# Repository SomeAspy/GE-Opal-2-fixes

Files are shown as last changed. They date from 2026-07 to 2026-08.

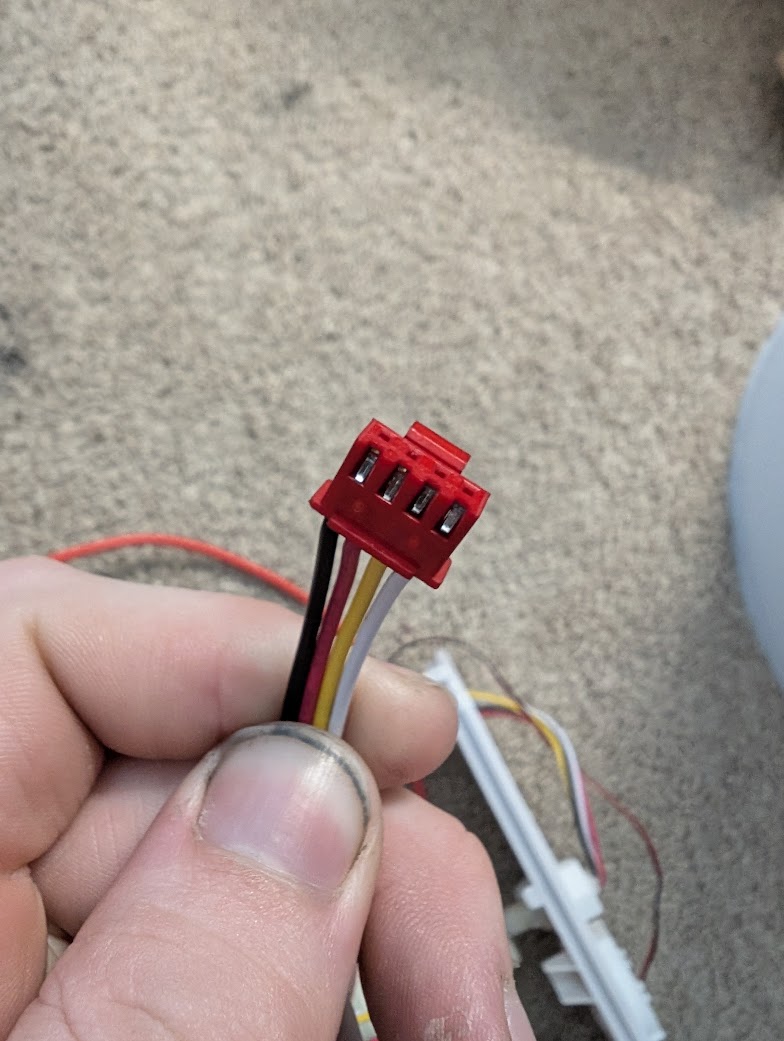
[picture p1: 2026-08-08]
images/floatConnector.jpg

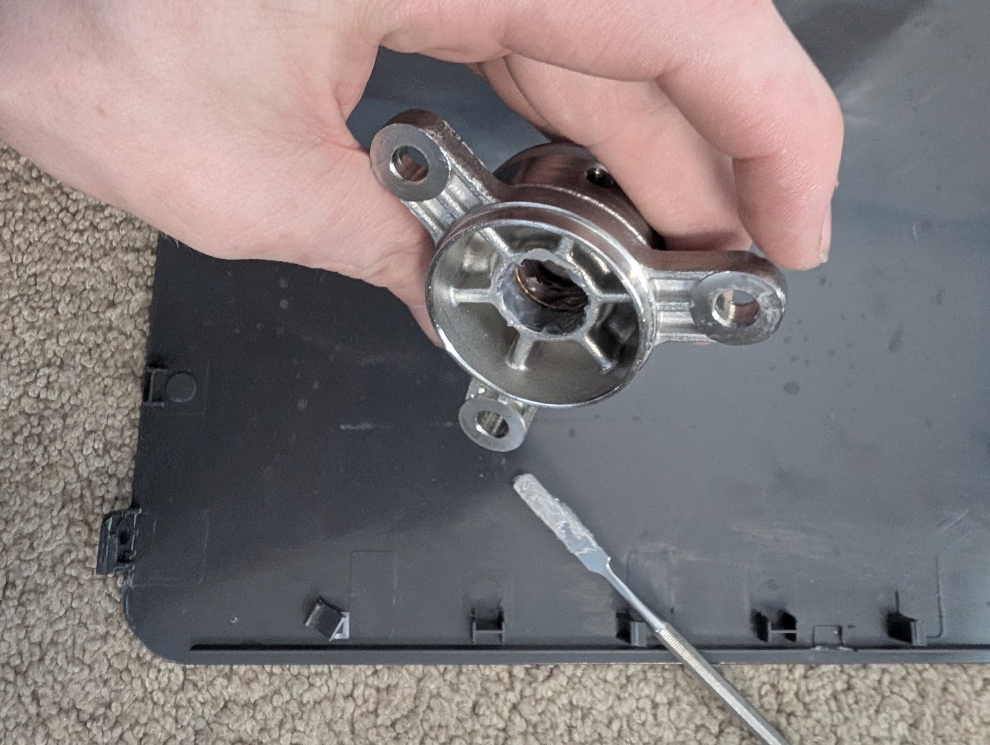
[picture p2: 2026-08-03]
images/greaseSpread.jpg

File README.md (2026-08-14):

# GE-Opal-2-fixes

This repository documents, all my attempts to make the GE Opal 2 not kill itself
(More specifically, the *GE Profile:tm: Opal:tm: 2.0 Ultra Nugget Ice Maker )

Important context to a lot of frustration here: This is a $500 dollar ice machine. It has a lifespan of 6 months to 1 year

> [!WARNING]  
> Schematics and code are not final or tested yet.

### Note on AI usage because I hate AI bullshit:

I used AI to help me understand the basics of KiCAD because I have never used it before.
I also used it to sanity check my code before I deployed it to the arduino, because I value not blowing my shit up.
I did **NOT** copy-paste code or otherwise use LLM generated material in this project.

The 2 calibration values where I used AI in the firmware are clearly marked.
If you are more skilled with calibration, your (human-made) contributions are welcome!

```cpp
augerMeter.current(MotorAmmeter, 5.76); // Calibration factor by gemini, because I hate complex math
const double currentDraw = augerMeter.calcIrms(1480); // IRM sample count by Gemini, because I can't be bothered.
```

Do **NOT** submit LLM generated issues, PRs, or use this repo in training data.

### My blog post on this

[A Scathing Review of the GE Opal 2 Nugget Ice Maker](https://blog.aspy.dev/a-scathing-review-of-the-ge-opal-2-nugget-ice-maker/)

# Background

I've tried putting lubrication on the auger ([./squeakFromShaft.md](./squeakFromShaft.md)) but it did not resolve the squeaking issue
I've decided I am going to replace the PCB with an arduino to implement a proper defrost cycle.

## Notice

As I was writing this, Reddit decided to delete the 2 year old post I was using as a reference.
Some of the more important images are available in ./images
https://web.archive.org/web/20250804095737/https://www.reddit.com/r/IceChewersAnonymous/comments/1hxlbkg/fixing_the_opal_20/

## The Problem

The GE Opal ice maker has well-known issues where it will start to fail after about a year of use, and in some cases, prior.
The machine is incredibly high maintenance, [with GE recommending running bleach through the machine](https://products.geappliances.com/appliance/gea-support-search-content?contentId=000060634) ([archive.org capture](https://web.archive.org/web/20260716162758/https://products.geappliances.com/appliance/gea-support-search-content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))

There is even (as of writing) [an ongoing class action](https://classlawdc.com/2026/01/21/ge-profile-opalnugget-ice-maker-series-1-0-and-2-0-defective-product-investigation/)

These machines do not fail gracefully, often making screeching and whining noises due to the internal parts getting frozen and locked up. This commonly involves the destruction of the gearbox, auger, and/or bearings.

Browsing Reddit reveals many owners have constant issues with these machines, with one redditor even claiming to go through 4 machines in 2 years. Despite its flaws, this machine is well liked by r/IceChewersAnonymous, though they also agree that it has significant longevity issues. [A quick search shows the love/hate the community has for it.](https://www.reddit.com/r/IceChewersAnonymous/search/?q=opal+2)

More importantly, several members of the community have taken attempts to repair the machine pretty far.

- https://www.reddit.com/r/IceChewersAnonymous/comments/1ophadu/opal_20_repair_update/
- https://www.reddit.com/r/IceChewersAnonymous/comments/1hxlbkg/fixing_the_opal_20/
- https://www.reddit.com/r/IceChewersAnonymous/comments/159ts6e/ge_opal_20_add_water_fix/

# Piping

Piping

# Nominal voltages recorded from the opal 2 ice maker during operation

| Part | Connector Type | Voltage |
| --- | --- | --- |
| UV Light | JST XH 2-pin connector  | 12V DC  |
| Compressor | JST VHR 3-pin connector | 120V AC |
| Auger Motor | JST VHR 3-pin connector | 120V AC |
| Pump | JST XH 2-pin connector  | 12V DC  |
| Fan | JST XH 2-pin connector  | 12V DC  |
| WiFi Board | TBD | TBD |
| Front Panel | TBD | TBD |
| Ice Box LED | JST XH 2-pin connector  | 5V DC |
| Ice box presence switch | JST XH 2-pin connector  | 5V DC |
| Internal Tank Floats | JST XH 4-pin connector  | 5V DC |
| IR LED For Capacity | JST XH 2-pin connector  | 5V DC |
| IR Receiver | JST XH 2-pin connector  | 5V DC |
| AC Input | JST VHR 3-pin connector | 120V AC |

- Internal Tank Floats (4 wires, 2 floats)
  - Black & Red: Lower float (float low = closed circuit)
  - Yellow & White: Upper float (float high = closed circuit)

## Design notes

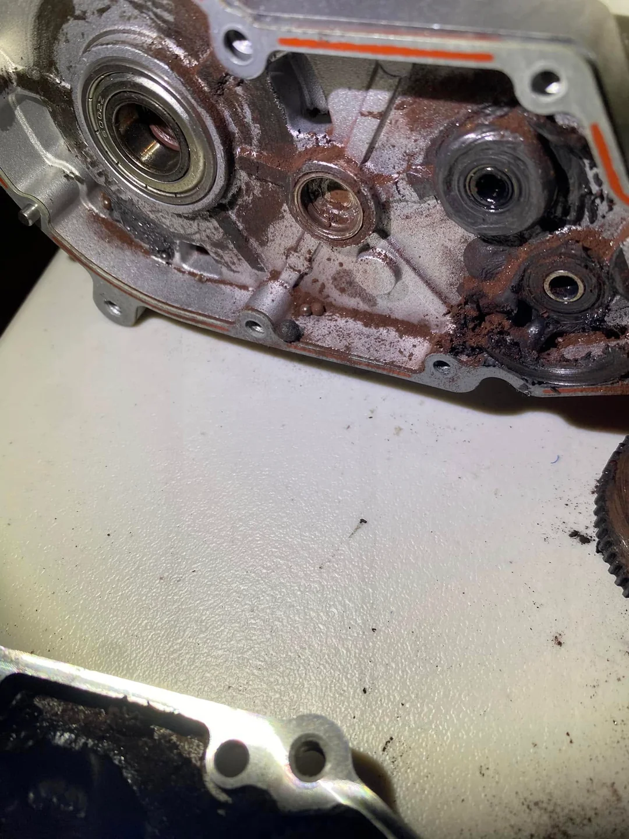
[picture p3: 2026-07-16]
images/shreddedGearbox.webp

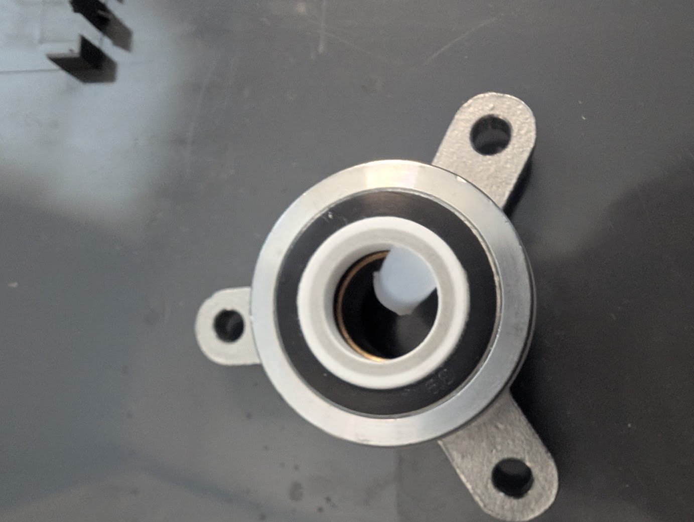
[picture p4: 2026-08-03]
images/greasedBushing.jpg

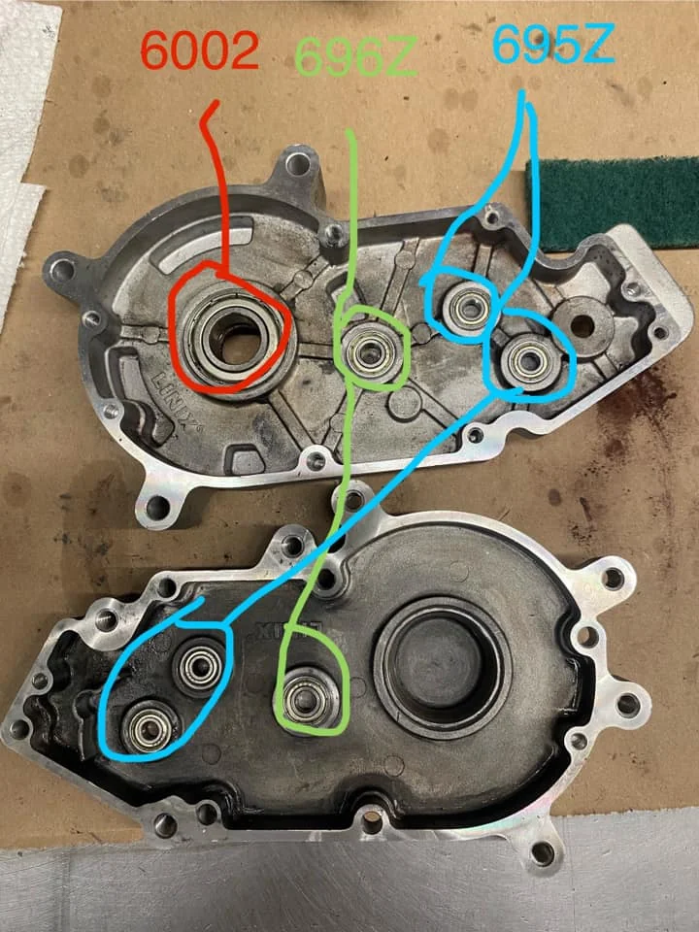
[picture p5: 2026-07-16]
images/bearingSizes.webp

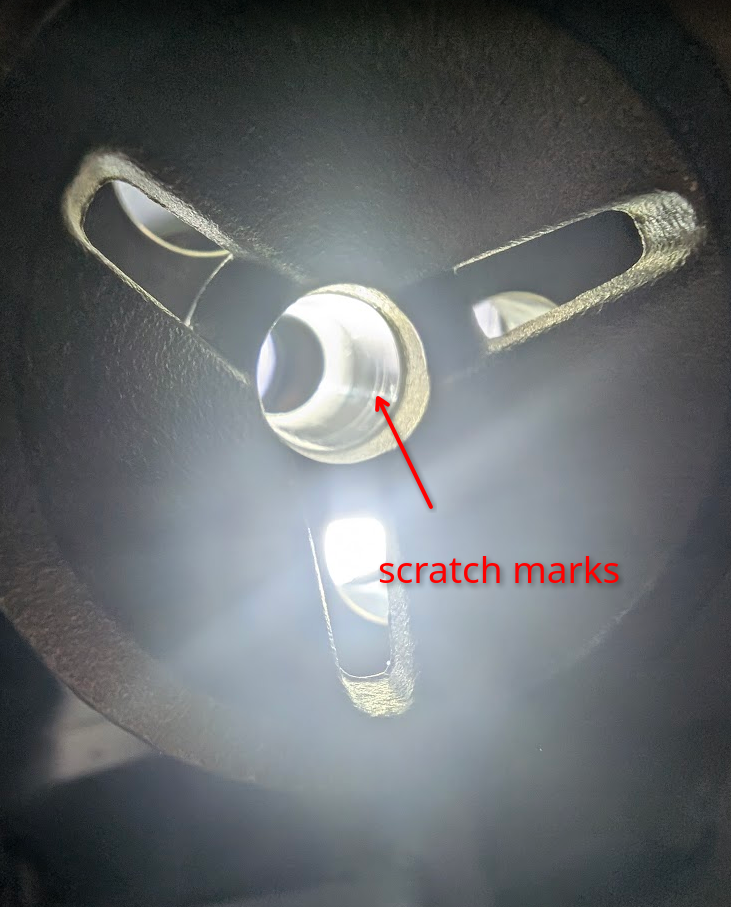
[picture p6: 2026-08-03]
images/scratchedBushing.png

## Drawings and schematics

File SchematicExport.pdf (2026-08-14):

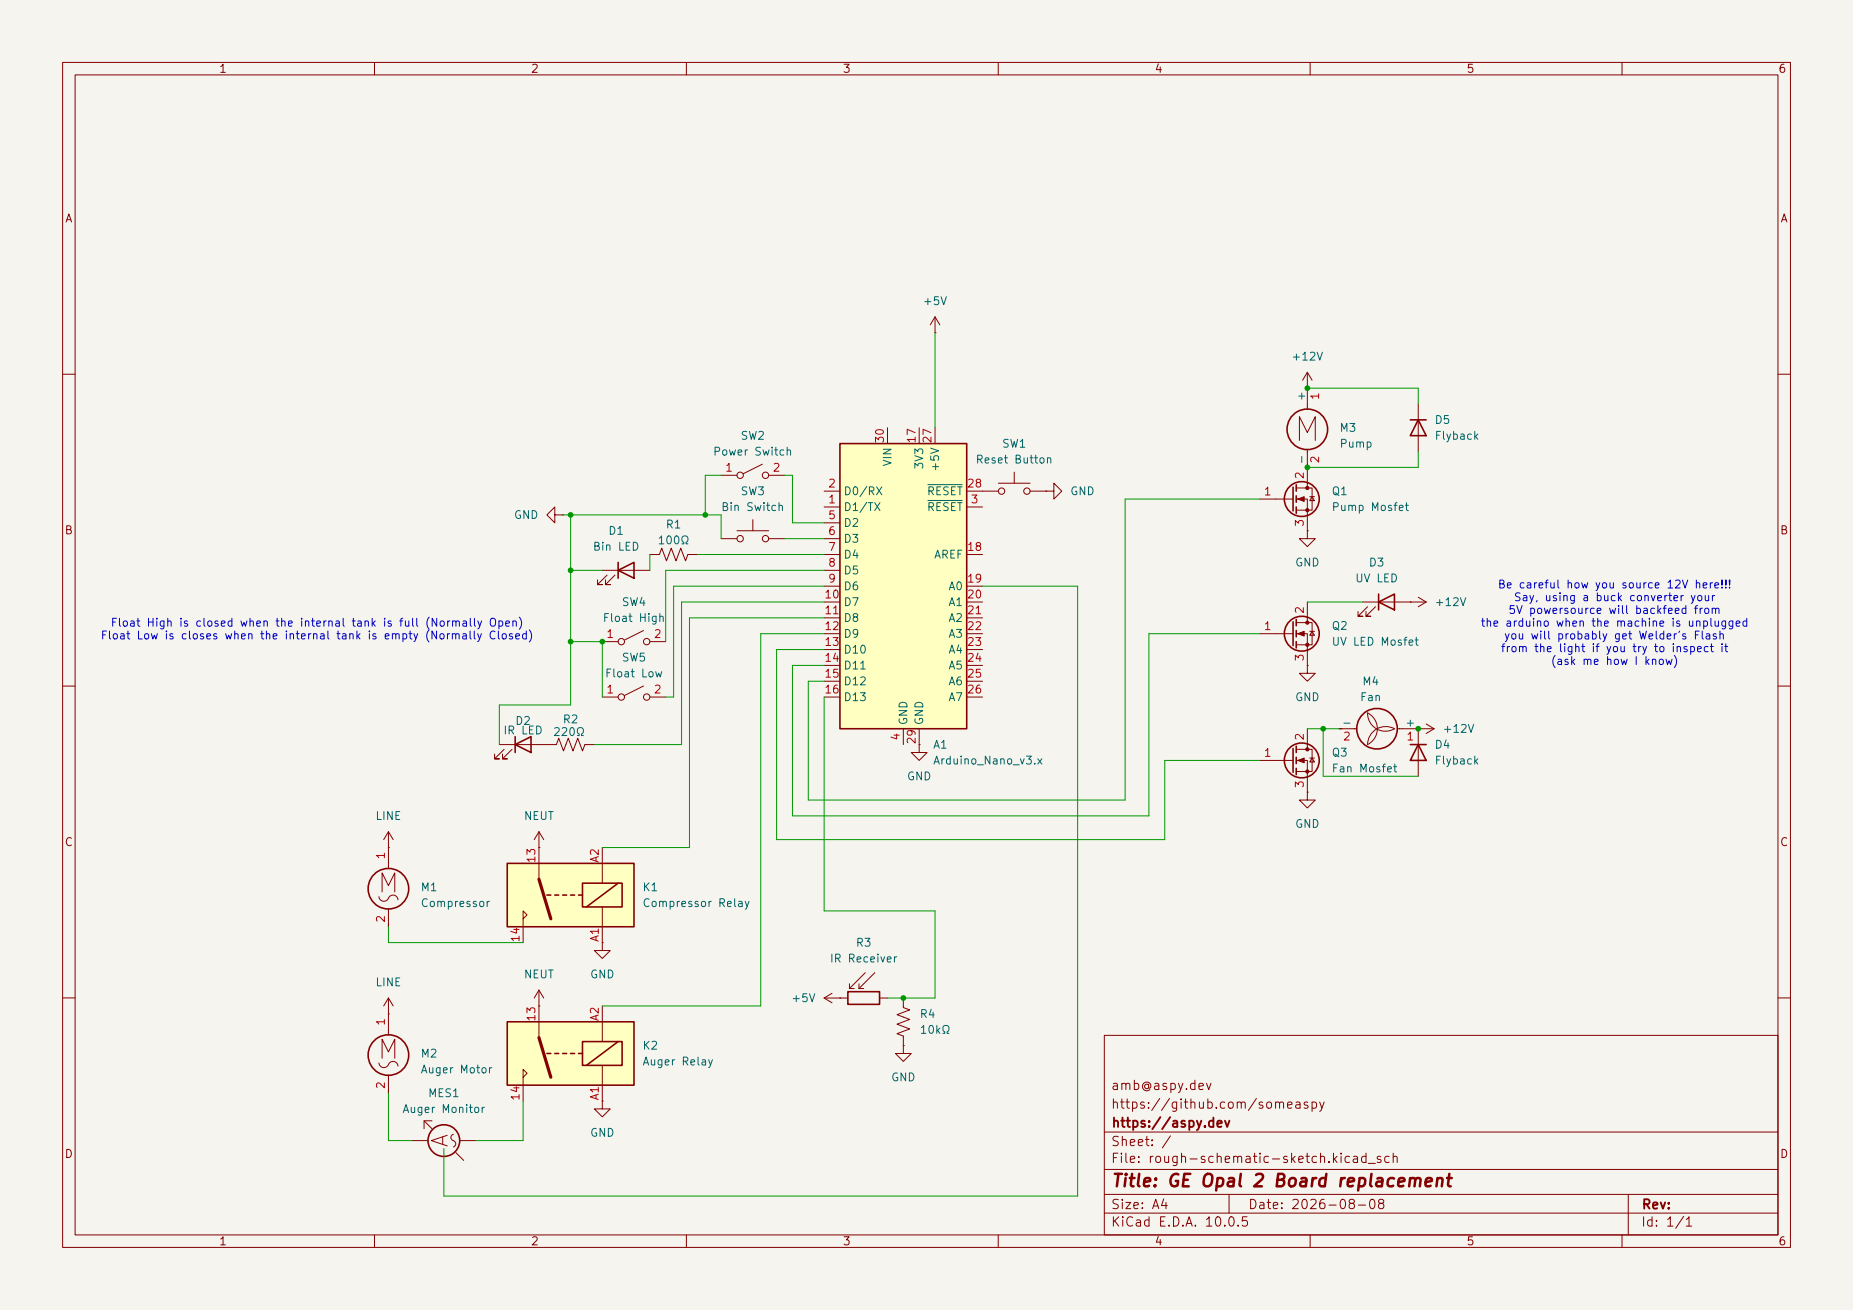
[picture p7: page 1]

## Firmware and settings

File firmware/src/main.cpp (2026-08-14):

// Copyright (C) 2026 SomeAspy (Aiden B. amb@aspy.dev)
// SPDX-License-Identifier: GPL-3.0-only
// https://github.com/someaspy/GE-Opal-2-fixes

#include <Arduino.h>
#include <EmonLib.h>

// Pins
const int PowerSwitch = 2;
const int BinSwitch = 3;
const int TankFull = 5;
const int TankEmpty = 6;
const int IrBlaster = 7;
const int Compressor = 8;
const int Auger = 9;
const int Fan = 10;
const int UvLed = 11;
const int Pump = 12;
const int IrReceiver = 13;
const int MotorAmmeter = A0;

// Run the compressor
// Run the auger
// Monitor the Ammeter
// Compressor needs cooldown

EnergyMonitor augerMeter;

void setup() {
  Serial.begin(115200);

  // Grounded inputs need to be pulled up
  pinMode(PowerSwitch, INPUT_PULLUP);
  pinMode(BinSwitch, INPUT_PULLUP);
  pinMode(TankFull, INPUT_PULLUP);
  pinMode(TankEmpty, INPUT_PULLUP);

  // Standard inputs
  pinMode(IrReceiver, INPUT);
  pinMode(MotorAmmeter, INPUT);

  // Outputs
  pinMode(IrBlaster, OUTPUT);
  pinMode(Compressor, OUTPUT);
  pinMode(Auger, OUTPUT);
  pinMode(Fan, OUTPUT);
  pinMode(UvLed, OUTPUT);
  pinMode(Pump, OUTPUT);
  augerMeter.current(
      MotorAmmeter,
      5.76); // Calibration factor by gemini, because I hate complex math
};

// Persistent Values
bool pumping = false;
bool waitingForReset = false;
const unsigned long pumpTimeout =
    120000; // 2m - may be a bit much but when the filter is installed waterflow
            // can drop significantly.
unsigned long pumpStartedTime = 0;
unsigned long compressorStopTime = 300001; // If the machine is off, assume its
                                           // been off for a safe amount of time
const unsigned long compressorTimeout = 300000; // 5m
bool isCompressorRunning = false;
unsigned long compressorStartTime = 0;

// From testing the machine usually settles around 0.45A to 0.48A.
// 0.05 means the compressor is off.
// Note currentDrawLimit is ignored when the compressor first starts to
// accomodate inrush current. Tweak as needed.
const float currentDrawLimit = 0.50;
const unsigned long compressorGracePeriod = 15000; // 15s for inrush to settle

bool defrostCycle = false;
const unsigned long defrostCycleLength = 600000; // 10m
unsigned long defrostCycleStartTime = 0;

void loop() {
  // DIGITAL READS ARE INVERTED BECAUSE WE PULL UP!!!
  const bool isPowered = digitalRead(PowerSwitch) == LOW;
  const bool isTankFull = digitalRead(TankFull) == LOW;
  const bool isTankEmpty = digitalRead(TankEmpty) == LOW;
  const bool isBinInserted = digitalRead(BinSwitch) == LOW;
  const double currentDraw = augerMeter.calcIrms(
      1480); // IRM sample count by Gemini, because I can't be bothered.

  Serial.println(currentDraw);

  if (!isPowered || waitingForReset || defrostCycle) {
    Serial.println("Halted");
    digitalWrite(Pump, LOW);
    digitalWrite(Compressor, LOW);
    digitalWrite(Fan, LOW);
    digitalWrite(UvLed, LOW);
    digitalWrite(IrBlaster, LOW);
    digitalWrite(Auger, LOW);
    if (isCompressorRunning) {
      compressorStopTime = millis();
      isCompressorRunning = false;
    }
    pumping = false;
    if (!isBinInserted) {
      waitingForReset = false;
    }
    if (millis() - defrostCycleStartTime > defrostCycleLength) {
      defrostCycle = false;
    }
    return;
  }

  if (pumping && (millis() - pumpStartedTime > pumpTimeout)) {
    // We are probably out of water
    Serial.println("no water?");
    waitingForReset = true;
    return;
  }

  if (isTankEmpty && !pumping) {
    digitalWrite(UvLed, HIGH);
    digitalWrite(Pump, HIGH);

    pumping = true;
    pumpStartedTime = millis();
  }

  if (isTankFull && pumping) {
    digitalWrite(UvLed, LOW);
    digitalWrite(Pump, LOW);
    pumping = false;
  }

  if (!isCompressorRunning) {
    if (millis() - compressorStopTime < compressorTimeout) {
      return;
    }
    digitalWrite(Compressor, HIGH);
    digitalWrite(Fan, HIGH);
    digitalWrite(Auger, HIGH);
    compressorStartTime = millis();
    isCompressorRunning = true;
  }

  if (currentDraw >= currentDrawLimit &&
      millis() - compressorStartTime > compressorGracePeriod) {
    defrostCycle = true;
    defrostCycleStartTime = millis();
  }
}

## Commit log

2026-08-03 add squeaking shaft fix
2026-08-08 pcb work progress
2026-08-08 schematic touchup and warning
    [rough-schematic-sketch.kicad_sch]
2026-08-08 remove kicad history
2026-08-09 water pump logic working
2026-08-14 a word of warning added to schematic
    [rough-schematic-sketch.kicad_sch]
